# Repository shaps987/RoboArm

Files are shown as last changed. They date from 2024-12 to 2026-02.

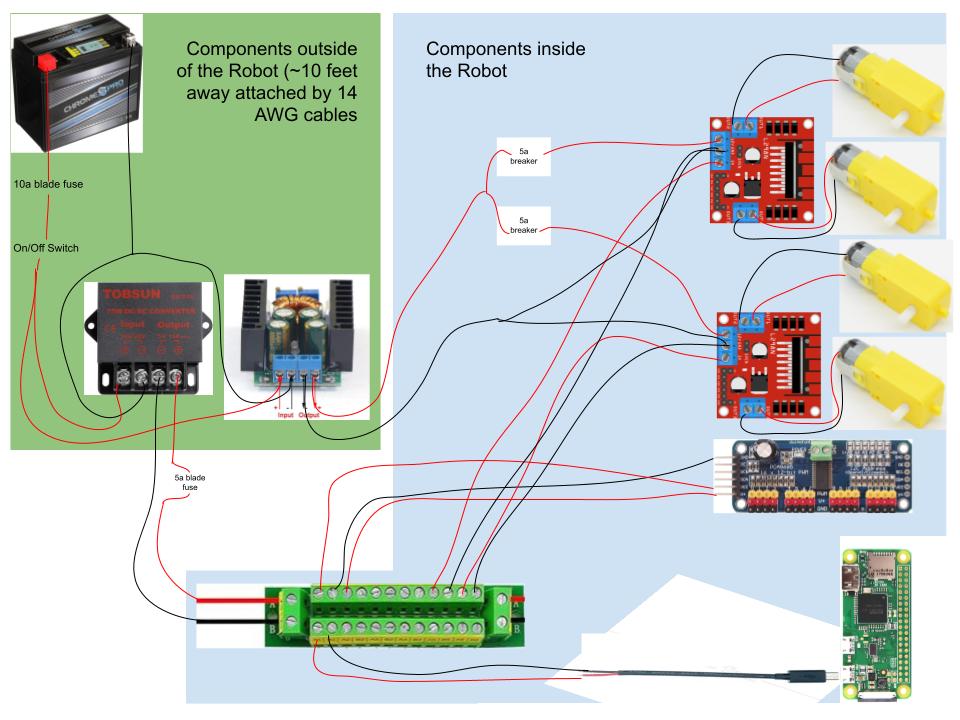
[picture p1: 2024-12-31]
Wiring/Robot/robot_wiring_diagram.jpg

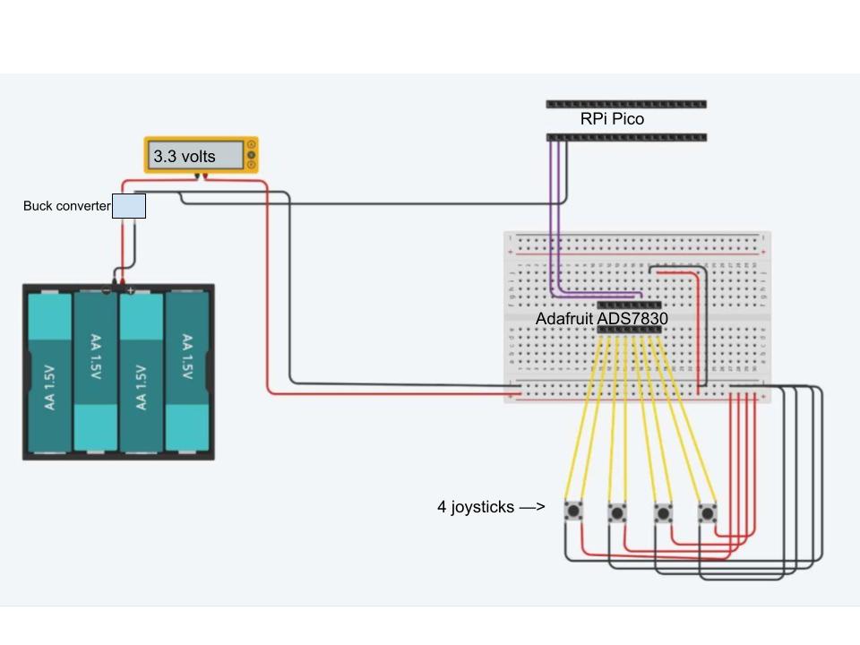
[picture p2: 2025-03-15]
Wiring/Remote/remote_wiring_diagram2.jpg

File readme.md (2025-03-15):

# RoboArm Project

## Overview
This project involves building a versatile and remotely controlled robotic arm, leveraging the power and flexibility of Raspberry Pi microcontrollers. The robotic arm is designed for precise movement and versatility, controlled remotely via a custom-built controller featuring multiple joysticks. The remote communicates with the robotic arm over Bluetooth Low Energy (BLE) for real-time command execution.

The **remote control** is powered by a Raspberry Pi Pico WH and includes an analog-to-digital converter to process joystick inputs. These joysticks allow intuitive control of the robotic arm's movements, including its base, joints, and claw.

The **robotic arm** itself is powered by a Raspberry Pi Zero WH, which coordinates the movements of servos and motors to execute commands received from the remote. With **inverse kinematics**, the robotic arm achieves smooth and accurate movement for tasks requiring precision. The arm is mounted on a mecanum wheel chassis, enabling it to move in all directions and navigate complex environments.

---

## Components

### Remote Control
- **Raspberry Pi Pico WH**: Used as the main controller for the remote.
- **Analog to Digital Converter (Adafruit ADS7830)**: Converts the analog signals from the joysticks to digital signals.
- **4 Joysticks**: Used to control the movement of the robotic arm.

### Robotic Arm
- **Raspberry Pi Zero WH**: Used as the main controller for the robotic arm.
- **4 Servos (MG996R)**:
  - 3 for the joints of the arm.
  - 1 for the claw's grippers.
- **2 Motor Controllers (L298N)**: Control a total of 4 mecanum wheel motors for the robotic arm's chassis.
- **Servo Controller (PCA9685)**: Controls the 4 servos.
- **1 12V Battery**: Powers the entire robotic arm system.
- **2 Buck Converters**:
  - One steps down from **12V to 5V** for logic circuits.
  - One steps down from **12V to 7V** for motor power.
- **Various Protection Devices**:
  - 1 **10A Slow-Blow Fuse** for the entire circuit.
  - 1 **5A Slow-Blow Fuse** for the logic circuit (RPi Zero, PCA9685 servo controller, and the logic inputs of both L298N motor drivers).
  - 2 **5A Circuit Breakers** for the motor circuits (one for each L298N).
- **Rocker Switch**

---

## Power Supply

### Remote Control
- Powered by a 6V 4 AA battery pack stepped down to 5V with a buck converter.

### Robotic Arm
- **12V Battery**:
  - The positive terminal is connected to a **10A slow-blow fuse**, chosen because the combined input current for the buck converters is ~7A, allowing for surges.
  - Powers two buck converters:
    - **Buck Converter #1 (5V)**:
      - Supplies the Raspberry Pi Zero, PCA9685, and logic inputs of both L298Ns.
      - Protected by a **5A slow-blow fuse**, chosen because the total current draw of these components is ~3.7A, with additional headroom for safety.
    - **Buck Converter #2 (7V)**:
      - Supplies the VIN inputs of both L298Ns for motor power.
      - Protected by **two 5A circuit breakers** (one per L298N motor driver, chosen because each driver can handle up to ~4A under normal operation, with peaks up to 5A during stalls or startups).

---

## Setup

### 1. Purchase Products
Here are the product links with their prices (prices may change):
| **Item** | **Price**  |
|---|---|
| [Chrome Battery YTX12-BS iGel](https://www.amazon.com/Chrome-Battery-iGel-12-BS-CYTX12-BS/dp/B01DOIULOO) | $39.90 |
| [Inline Blade Fuse Holder Set](https://www.amazon.com/GNAWRISHING-Inline-Holder-Standard-Assorted/dp/B09Y8GB799) | $8.99 |
| [5A Circuit Breaker (2-Pack)](https://www.amazon.com/mxuteuk-Breakers-Protector-Terminals-Waterproof/dp/B08QVCYLMD) | $9.99 |
| [Rocker Switch](https://www.amazon.com/gp/product/B07XD8J2PL) | $8.99 |
| [12V to 5V Buck Converter](https://www.amazon.com/VOLRANTISE-Converter-Voltage-Regulator-Transformer/dp/B09X1ZGR38) | $11.98 |
| [Adjustable Buck Converter (12V to 7V)](https://www.amazon.com/Converter-DROK-Adjustable-Regulator-Indicator/dp/B00HHQ0VP4) | $16.11  |
| [Power Distribution Board](https://www.amazon.com/Tnisesm-Position-Distribution-Inputs-Outputs/dp/B0BWN19R6R) | $8.99 |
| [Micro USB to Pigtail Cable](https://www.amazon.com/gp/product/B0BZ8XWL18/ref=ewc_pr_img_4?smid=A1PP7IW2YCJN73&psc=1) | $9.59 |
| [Raspberry Pi Zero WH](https://www.amazon.com/Raspberry-Bluetooth-Compatible-Connector-headers/dp/B0CG99MR5W) | $21.98 |
| [Momentary Push Button Switch with LED (5-pack)](https://www.amazon.com/Momentary-Indicator-Pushbutton-Waterproof-Stainless/dp/B08L13JG8M/) | $13.98 |
| [L298N Motor Drivers (4-pack)](https://www.amazon.com/gp/product/B0CR6MLY7F/ref=ewc_pr_img_7?smid=A1YZW40LYQY3L1&psc=1) | $9.99 |
| [Mecanum Wheels and Motors (4-pack)](https://www.amazon.com/gp/product/B0CBJJM1KQ/ref=ewc_pr_img_3?smid=A2S878EGP30YQG&th=1) | $15.60  |
| [PCA9685 Servo Driver (2-pack)](https://www.amazon.com/gp/product/B07BRS249H/ref=ewc_pr_img_8?smid=A30QSGOJR8LMXA&psc=1) | $13.99  |
| [MG996R Servos (4-Pack)](https://www.amazon.com/2-Pack-MG996R-Torque-Digital-Helicopter/dp/B0D7M2Y2BR) | $16.89 |
| [Adafruit 4 AA Battery Pack](https://www.adafruit.com/product/830) | $2.95 |
| [Adafruit Raspberry Pi Pico WH](https://www.adafruit.com/product/5544) | $7.00 |
| [Adafruit ADS7830 Analog to Digital Converter](https://www.adafruit.com/product/5836) | $5.95 |
| [Joysticks (6-pack)](https://www.amazon.com/gp/product/B0DH2G1PVP/ref=ewc_pr_img_6?smid=A3EW69KEBHQF24&psc=1) | $5.99 |
| [XT30 Connectors (8 pairs)](https://www.amazon.com/Pairs-Female-Connector-Silicone-Battery/dp/B07C5KJX24/) | $12.99 |

#### **Total Price: ~$243**

### 2. **Assemble the Remote Control**

- Connect the joysticks to the analog-to-digital converter.
- Connect the converter to the Raspberry Pi Pico.
- Power the Pico with the 6V battery pack stepped down to 5V.

### 3. **Assemble the Robotic Arm**
   - Connect the servos to the servo controller.
   - Connect the motor controllers to the mecanum wheel motors.
   - Connect the servo controller and motor controllers to the Raspberry Pi Zero.
   - Wire the **12V battery** as follows:
     - Connect the positive terminal to a **10A slow-blow fuse** then to a **rocker switch** and then split to two buck converters.
     - **Buck Converter #1 (5V)**:
       - Connect the positive output to the Raspberry Pi Zero, PCA9685, and logic inputs of both L298Ns.
       - Use a **5A slow-blow fuse** after the buck converter.
     - **Buck Converter #2 (7V)**:
       - Split the positive output into two separate wires, each passing through a **5A circuit breaker** before connecting to the VIN inputs of each L298N motor driver.
   - Use **14 AWG wires** for connections between the battery and the buck converters and from the buck converters along the ~10 feet (one-way) long powerline to the moving robot.
   - Use **18 AWG wires** for connections from the power distribution board to the components inside the robot.

---

## Usage
- Use the joysticks on the remote control to send signals to the Raspberry Pi Zero.
- The Raspberry Pi Zero processes these signals to control the servos and motors, moving the robotic arm accordingly.

---

## Future Improvements
- Add more sensors for better control and feedback.
- Enhance the software for more precise movements and automation.

---

## License
This project is licensed under the MIT License.

---

## Acknowledgements
Special thanks to the wonderful internet for providing many valuable resources for this project.

---

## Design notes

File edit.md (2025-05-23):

# Robotic Arm with nRF24L01⁺ (Pico ↔ nRF52840 Sense)

This README describes how to rewire and modify your project to use an **nRF24L01⁺** wireless transceiver instead of BLE, with:

- **Robot:** Raspberry Pi Pico running MicroPython  
- **Remote:** nRF52840 Sense running CircuitPython

---

## 1. Robot (Raspberry Pi Pico + MicroPython)

### 1.1 Wiring / Pin-out

| Function | Pico GP# | Physical Pin | Notes |
| --- | :---: | :---: | --- |
| **nRF24L01⁺**  | | | |
| VCC | — | 36 | 3.3 V |
| GND | — | 38 | Ground |
| CE | GP14 | 19 | Digital GPIO |
| CSN | GP15 | 20 | Active-low CS |
| SCK | GP18 | 24 | SPI0 SCK |
| MOSI | GP19 | 25 | SPI0 MOSI |
| MISO | GP16 | 21 | SPI0 MISO |
| **PCA9685** | | | |
| SDA | GP0 | 1 | I2C0 SDA |
| SCL | GP1 | 2 | I2C0 SCL |
| **L298N #1** | | | Controls 2 motors|
| IN1 | GP2 | 4 | |
| IN2 | GP3 | 5 | |
| IN3 | GP4 | 6 | |
| IN4 | GP5 | 7 | |
| ENA (PWM) | GP6 | 9 | PWM0 CH0 |
| ENB (PWM) | GP7 | 10 | PWM0 CH1 |
| **L298N #2** | | | Controls 2 motors|
| IN1 | GP8 | 11 | |
| IN2 | GP9 | 12 | |
| IN3 | GP10 | 14 | |
| IN4 | GP11 | 15 | |
| ENA (PWM) | GP12 | 16 | PWM0 CH2 |
| ENB (PWM) | GP13 | 17 | PWM0 CH3 |

---

### 1.2 Code Edits

1. **Remove BLE-related imports and `asyncio` logic**  
```python
# Remove these:
from bleak import BleakScanner, BleakClient
import asyncio
# and any `async def` connect_to_remote(), peripheral_task(), etc.
```

2. **Import nRF24L01⁺ and initialize SPI and RX logic**  
```python
import board, busio, digitalio, time
from adafruit_nrf24l01 import NRF24L01

spi = busio.SPI(board.SCK, board.MOSI, board.MISO)
ce = digitalio.DigitalInOut(board.GP14)
csn = digitalio.DigitalInOut(board.GP15)
radio = NRF24L01(spi, csn, ce, channel=100, payload_size=1)
radio.open_rx_pipe(0, b'\xe1\xf0\xf0\xf0\xf0')
```

3. **Replace BLE connection and main loop with a blocking `while True:` that reads from `radio`**  
```python
while True:
    if radio.available():
        buf = radio.read(1)
        cmd = bytes(buf)
        move_robot(cmd)
    time.sleep(0.1)
```

4. **Delete all BLE callbacks, `async def` functions, and BLE-specific error handling**

---

## 2. Remote (nRF52840 Sense + CircuitPython)

### 2.1 Wiring / Pin-out

| Function | Board Pin | Notes |
| --- | --- | --- |
| **ADS7830** | | |
| VCC | 3V3 | |
| GND | GND | |
| SDA | SDA | I²C SDA |
| SCL | SCL | I²C SCL |
| **nRF24L01⁺**  | | |
| VCC | 3V3 | |
| GND | GND | |
| CE | D5 | Digital IO |
| CSN | D6 | Active-low CS |
| SCK | SCK | SPI SCK |
| MOSI | MOSI | SPI MOSI |
| MISO | MISO | SPI MISO |

---

### 2.2 Code Edits

1. **Remove BLE-related imports and logic**  
```python
# Remove these:
from bleak import BleakScanner, BleakClient
import asyncio
# and any `async def` connect_to_remote(), peripheral_task(), etc.
```

2. **Import nRF24L01⁺ and initialize SPI and TX pipe**  
```python
import board, busio, digitalio, time
from adafruit_nrf24l01 import NRF24L01

spi = busio.SPI(board.SCK, board.MOSI, board.MISO)
ce = digitalio.DigitalInOut(board.D5)
csn = digitalio.DigitalInOut(board.D6)
radio = NRF24L01(spi, csn, ce, channel=100, payload_size=1)
radio.open_tx_pipe(b'\xe1\xf0\xf0\xf0\xf0')
```

3. **Replace BLE `notify` calls with `radio.send()` logic inside a `while True:`**  
```python
last_cmd = None
while True:
    val = ads.read(1)  # joystick forward/back
    if val > 148:
        cmd = b"f"
    elif val < 108:
        cmd = b"b"
    else:
        cmd = None

    if cmd and cmd != last_cmd:
        radio.send(cmd)
        last_cmd = cmd

    time.sleep(0.1)
```

4. **Delete `async def` functions and all BLE-specific control flow**

---

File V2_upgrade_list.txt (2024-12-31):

V2 Upgrade Suggestions

1. Add Limit Switches:
   - Install limit switches for safety and precise control at the arm's movement limits.
   - Connect to GPIO pins to detect end stops.

2. Improve Motor Control:
   - Upgrade L298Ns to motor drivers with higher efficiency (e.g., TB6612FNG) to reduce heat and improve performance.

3. Feedback Systems:
   - Add potentiometers or encoders to track servo/motor positions in real-time.

4. Battery Monitoring:
   - Use a voltage divider with an ADC or a dedicated battery monitoring IC to display battery level on the controller.

5. OLED Screen:
   - Add a 1.3-inch OLED screen to display status information (e.g., battery level, connection status).

6. Wi-Fi Connectivity:
   - Add a Wi-Fi module (e.g., ESP8266) for remote control and telemetry.

7. Sensor Integration:
   - Include sensors like ultrasonic or IR distance sensors for obstacle detection.

8. Camera Support:
   - Attach a Pi Camera for vision-based control or remote viewing.

9. Advanced Inverse Kinematics:
   - Improve software to handle more complex arm movements and path planning.

10. Voice Commands:
    - Add a microphone and integrate voice control using AI libraries (e.g., Google Speech-to-Text).

11. Chassis Upgrade:
    - Use better wheels or motors for smoother and more stable movement.

12. Parallel Movement Commands:
    - Enable the arm to process multiple movement commands simultaneously by placing each movement under its own asyncio task.

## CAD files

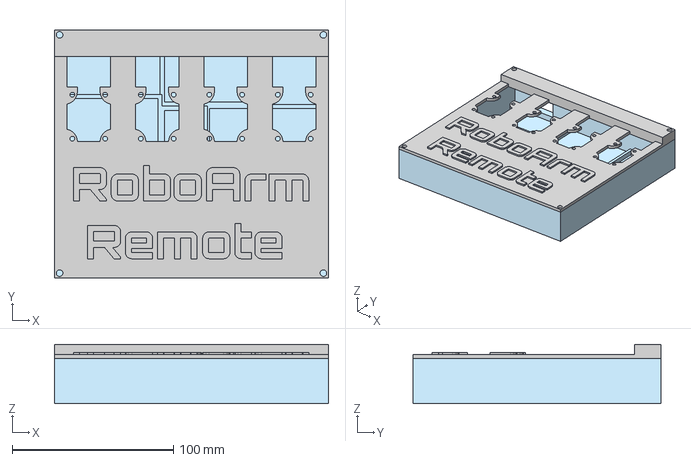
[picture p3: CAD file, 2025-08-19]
CAD Files/Remote/remote_assembled.step
169.9 x 154.1 x 36.8 mm

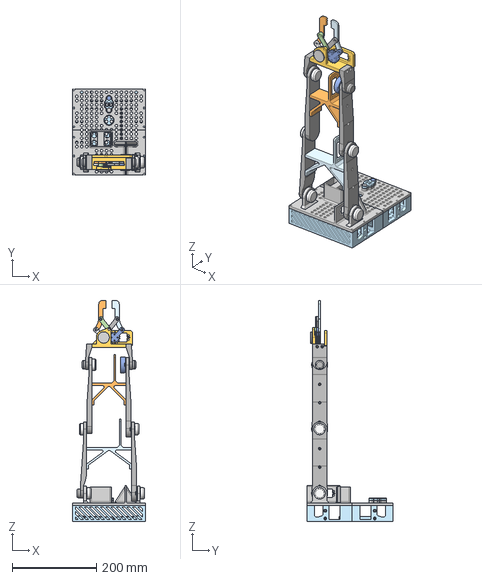
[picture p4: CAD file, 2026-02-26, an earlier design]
Archive/CAD Files OLD/Robot/robot_assembled.step
172.7 x 204.6 x 523.9 mm

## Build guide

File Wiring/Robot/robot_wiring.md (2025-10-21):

# Robotic Arm Wiring Description

---

### 12V 10.5Ah Battery(Power Source)

- **Amperage Usage**: Supplies ~7A for both buck converters.
- **Purpose**: Powers two buck converters, stepping down to **5V** for the logic circuits and **7V** for the motor inputs.
- **Connections**:
  - **Positive (+)**:
    - Connect to a **10A slow-blow fuse** (chosen because the total current draw from both buck converters is ~7A, allowing a safe margin for surges).
    - From the fuse, connect to a **rocker switch** using the wires pre-soldered to the switch.
    - After the switch, split the positive line into two separate connections for the two buck converters.
    - Use 18 AWG wire for connections up to the switch and split point.
  - **Negative (-)**:
    - Split the negative line and connect to the negative input of both buck converters.
    - Use 14 AWG wire to minimize voltage drop.

---

### Buck Converter #1 (5V for Logic Circuits)

- **Amperage Usage**: Draws ~5.4A at 5V.
  - **Breakdown**:
    - **L298N Logic**: ~0.1A (50mA × 2 motor drivers).
    - **Raspberry Pi Pico**: ~0.2A.
    - **PCA9685 Servo Controller (Logic)**: ~0.3A.
    - **Servos (MG996R)**: ~4.8A (1.2A × 4 servos).
    - **Momentary LED Push Button**: ~20mA when lit.
- **Purpose**: Steps down 12V to 5V for powering the Raspberry Pi Pico, PCA9685, and L298N logic circuits.
- **Connections**:
  - **Input**:
    - **Positive (+)**: Connect to the + terminal of the 12V battery via the split positive wire.
    - **Negative (-)**: Connect to the negative terminal of the 12V battery via the split negative wire.
    - Use 14 AWG wires for input.
  - **Output (5V)**:
    - Pass through a **5A slow-blow fuse** (chosen because the total current draw of the Raspberry Pi Pico, PCA9685, and L298N logic inputs is ~3.7A at 5V, with additional headroom for safety).
    - Use 14 AWG ~10 foot long cables to bring power to the moving robot from the buck converter.
      - Connect to a power distribution block:
        - **Positive (+)**:
          - The 5V logic input of both L298Ns.
          - The 5V input of the Raspberry Pi Pico.
          - The 5V input of the PCA9685 servo controller.
          - Use 18 AWG wires for these connections.
        - **Negative (-)**:
          - The GND terminal on both L298Ns.
          - The GND wire for the Raspberry Pi Pico's power.
          - The GND terminal on the PCA9685 servo controller.
          - Use 18 AWG wires for these connections.

---

### Buck Converter #2 (7V for Motor Inputs)

- **Amperage Usage**: Supplies ~4.8A for motor inputs.
- **Purpose**: Steps down 12V to 7V for powering the VIN inputs on both L298Ns.
- **Connections**:
  - **Input**:
    - **Positive (+)**:
      - Connect to the + terminal of the 12V battery via the split positive wire.
      - Use **14 AWG wires** for this connection.
    - **Negative (-)**:
      - Connect to the negative terminal of the 12V battery via the split negative wire.
      - Use **14 AWG wires** for this connection.
  - **Output (7V)**:
    - **Positive (+)**:
      - Split the **14 AWG wire** into two **18 AWG wires**.
      - Pass each of the **18 AWG wires** through a **5A circuit breaker**, one for each motor driver.
      - Connect the output of each breaker to the VIN input of its respective **L298N motor driver**.
    - **Negative (-)**:
      - Split the negative wire and connect to the GND terminals of both motor drivers using **18 AWG wire**.

---

### Momentary Push Button with LED

- **Amperage Usage**: The LED draws ~20mA when lit.
- **Purpose**: Allows the user to safely stop the script and shut down the Raspberry Pi.
- **Connections**:
  - **Positive (+)**:
    - Connect the LED positive terminal (red wire) to the 5V output of the power distribution block.
  - **Negative (-)**:
    - Connect the LED negative terminal (black wire) to the GND on the power distribution block.
  - **NO (Blue)**:
    - Connect the Normally Open terminal to a GPIO pin on the Raspberry Pi Zero.

---

### L298N Motor Drivers

1. **L298N #1**:
   - **Amperage Usage**:
     - **VIN (Motor Power Input)**: Draws ~1.2A during normal operation to power two motors.
     - **5V Logic Input**: Draws ~0.05A (50mA) to power the logic circuitry.
   - **Connections**:
     - **VIN (Motor Power Input)**:
       - Connect to the 7V output of the second buck converter after its dedicated **5A slow-blow fuse**.
       - Use 14 AWG wire.
     - **5V Logic Input**:
       - Connect to the +5V output of the first buck converter after the combined **5A slow-blow fuse**.
       - Use 18 AWG wire.
     - **GND**:
       - Connect to the GND output of the first buck converter.
       - Connect to the GND output of the second buck converter.
       - Use 18 AWG wire.

2. **L298N #2**:
   - **Amperage Usage**:
     - **VIN (Motor Power Input)**: Draws ~1.2A during normal operation to power two motors.
     - **5V Logic Input**: Draws ~0.05A (50mA) to power the logic circuitry.
   - **Connections**:
     - **VIN (Motor Power Input)**:
       - Connect to the 7V output of the second buck converter after its dedicated **5A slow-blow fuse**.
       - Use 14 AWG wire.
     - **5V Logic Input**:
       - Connect to the +5V output of the first buck converter after the combined **5A slow-blow fuse**.
       - Use 18 AWG wire.
     - **GND**:
       - Connect to the GND output of the first buck converter.
       - Connect to the GND output of the second buck converter.
       - Use 18 AWG wire to connect to the respective 14 AWG wire bringing power from the buck converter to the robot.

---

### Raspberry Pi Pico

- **Purpose**: Controls the robotic arm's servos and motor drivers (L298Ns).
- **Connections**:
  - **5V Power Input**:
    - Connect to the +5V output of the first buck converter through the **power distribution block**.
    - Use 18 AWG wire.
  - **GND**:
    - Connect to the GND output of the first buck converter through the **power distribution block**.
    - Use 18 AWG wire.

---

### PCA9685 Servo Controller

- **Amperage Usage**: Draws ~0.3A at 5V (logic only; servos powered separately).
- **Purpose**: Controls the servos on the robotic arm.
- **Connections**:
  - **5V Power Input**:
    - Connect to the +5V output of the first buck converter through the **power distribution block**.
    - Use 18 AWG wire.
  - **GND**:
    - Connect to the GND output of the first buck converter through the **power distribution block**.
    - Use 18 AWG wire.
  - **Servo Pins**:
    - Connect the servos (e.g., MG996R) directly to the PCA9685.

---

### Servos (MG996R)

- **Amperage Usage**: Draws ~1.2A per servo at 5V (when loaded; ~0.5A idle).
- **Purpose**: Provide movement for the robotic arm joints and claw.
- **Connections**:
  - **Power, GND, and PWM**:
    - Powered and controlled directly by the PCA9685.
    - Servos come with built-in wires and connectors.

---

### Motors (TT Motors via L298N)

- **Amperage Usage**: Each motor draws ~1.2A at 7V (under normal load; peaks ~3A).
- **Purpose**: Drive the robot chassis with mecanum wheels.
- **Connections**:
  - Each motor is connected to one of the motor output terminals on the L298Ns:
    - **Motor 1**: L298N #1 Output 1 & Output 2.
    - **Motor 2**: L298N #1 Output 3 & Output 4.
    - **Motor 3**: L298N #2 Output 1 & Output 2.
    - **Motor 4**: L298N #2 Output 3 & Output 4.
  - Use 18 AWG wires for motor connections.

---

### Wiring Chart - THE FOLLOWING PINS ARE OUTDATED (THEY ARE FOR THE RPI ZERO VERSION, NOT THE PICO VERSION)
Voltage Distribution Unit:
  - Positive Terminal of Battery: To 10A Fuse
  - Negative Terminal of Battery: Splits and goes to the 2 buck converters
  - 10A Fuse: To switch
  - Switch: splits and goes to the 2 buck converters
  - 7V Buck Converter Positive Output: To robot, then splits into two wires. Each wire has a 5A fuse on it. And then each fuse goes into the 12V pin on its respective L298N
  - 7V Buck Converter Negative Output: To robot, then splits into two wires. Then each wire goes into the 12V pin on its respective L298N
Motor Driver 1:
  - ENA: Pin 32, GPIO12
  - IN1: Pin 29, GPIO5
  - IN2: Pin 31, GPIO6
  - ENB: Pin 33, GPIO13
  - IN3: Pin 35, GPIO19
  - IN4: Pin 37, GPIO26

Motor Driver 2:
  - ENA: Pin 12, GPIO18
  - IN1: Pin 16, GPIO23
  - IN2: Pin 18, GPIO24
  - ENB: Pin 22, GPIO25
  - IN3: Pin 13, GPIO27
  - IN4: Pin 15, GPIO22

PCA9685:
  - SDA: Pin 3, GPIO2
  - SCL: Pin 5, GPIO3
  - VCC: 3.3v pin on Raspberry Pi Pico
  - GND: Ground pin on Raspberry Pi PIco
  - V+ (on the PCA9685 terminal block): 5V distribution block
  - GND (on the PCA9685 terminal block): 5V distribution block

NRF24L01:
  - VCC: Pin 36
  - GND: Pin 38
  - CE: Pin 19, GPIO 14
  - CSN: Pin 20, GPIO 15
  - SCK: Pin 24, GPIO 18
  - MOSI: Pin 25, GPIO 19
  - MISO: Pin 21, GPIO 16
  - IRQ: Not used

5V Distribution Block:
  - +/- Input: 5V Buck Converter +/- Output
  - +/- Outputs:
    - To Raspberry Pi Pico via a Pigtail to Micro-USB cable
    - To L298N #1 5V Logic Input and GND terminals
    - To L298N #2 5V Logic Input and GND terminals
    - To PCA9685 +/- V+ terminal block

### Final Checklist

1. **12V Battery** powers both buck converters:
   - Buck Converter #1 (5V): Supplies the Raspberry Pi Pico, PCA9685, and L298N logic inputs.
   - Buck Converter #2 (7V): Supplies the VIN inputs (motor power) on both L298Ns.
2. **Fuses**:
   - **10A Slow-Blow Fuse**: Protects the entire circuit, chosen because the combined input current for both buck converters is ~7A.
   - **5A Slow-Blow Fuse** (Logic Circuit): Protects the Raspberry Pi Pico, PCA9685, and L298N logic inputs.
   - **5A Slow-Blow Fuses** (Motor Drivers): One fuse per L298N motor driver, chosen because each driver can handle up to ~4A continuously with peaks up to 5A during stalls or startups.
3. **Switch**:
   - Use an 18 AWG wire to connect the positive terminal of the battery to the switch and the switch to the fuse.
4. **Wiring to the Robot**:
   - Use 14 AWG wires for the long runs to the robot's power distribution blocks.
   - Inside the robot, use 18 AWG wires to connect components to the distribution blocks.

---

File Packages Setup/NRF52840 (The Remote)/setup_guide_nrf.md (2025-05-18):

# nRF52840 BLE Project Setup with ADS7830 and CircuitPython

This guide walks you through flashing firmware, setting up libraries, wiring the hardware, and loading the code for your nRF52840 board running CircuitPython with BLE support and an ADS7830 sensor.

---

## 1. Flash CircuitPython Firmware

1. **Download Firmware:**
   - Visit [CircuitPython Downloads](https://circuitpython.org/downloads) and locate the appropriate UF2 file for your nRF52840 board.
   - **Note:** If you're using a board like the Adafruit nRF52840 Sense, use its UF2 file. For other variants (e.g., Seeed Studio XIAO nRF52840), you may need a custom or community-provided firmware.

2. **Enter Bootloader Mode:**
   - For many nRF52840 boards, double‑tap the reset button. The board will appear as a USB mass storage device (commonly named **CIRCUITPY**).

3. **Copy the UF2 File:**
   - Drag and drop the UF2 file onto the board’s drive. The board will reboot into CircuitPython.

---

## 2. Prepare Your Libraries

1. **Create or Update the `lib` Folder:**
   - On the **CIRCUITPY** drive, ensure there is a folder named `lib`.

2. **Download Required Libraries:**
   - Just take the pre-made lib folder in this github repository (its in packages setup -> nrf52840 (the remote) -> files -> lib)

---

## 3. Hardware Wiring

### ADS7830 Sensor
- **Power:** Connect the ADS7830 VDD to your board’s 3.3V output and GND to the board’s ground.
- **I2C Lines:**
  - **SDA:** Connect ADS7830 SDA to the board’s SDA pin (usually referenced as `board.SDA`).
  - **SCL:** Connect ADS7830 SCL to the board’s SCL pin (usually referenced as `board.SCL`).

### LED Indicator (Optional)
- Most boards include a built-in LED referenced as `board.LED`. Confirm with your board's documentation.

---

## 4. Write and Load Your Code

1. **Create Your Main Script:**
   - On the **CIRCUITPY** drive, create a file named `code.py`.

2. **Paste the Following Code into `code.py`:**

   ```python
    import board
    import digitalio
    import busio
    import microcontroller
    import asyncio

    # --- BLE Imports from Adafruit Libraries ---
    from adafruit_ble import BLERadio, Service
    from adafruit_ble.advertising.standard import ProvideServicesAdvertisement
    from adafruit_ble.characteristics import Characteristic
    from adafruit_ble.uuid import StandardUUID
    from adafruit_ble.services.standard.device_info import DeviceInfoService

    # I²C address discovered by scan
    ADS7830_ADDR = 0x48

    # --- I2C Setup for ADS7830 ---
    i2c = busio.I2C(board.SCL, board.SDA)
    ads7830_commands = (0x84, 0xC4, 0x94, 0xD4, 0xA4, 0xE4, 0xB4, 0xF4)

    def read_ads7830(channel):
        """Read one byte from the given ADS7830 channel over I2C."""
        while not i2c.try_lock():
            pass
        try:
            i2c.writeto(ADS7830_ADDR, bytes([ads7830_commands[channel]]))
            buf = bytearray(1)
            i2c.readfrom_into(ADS7830_ADDR, buf)
            return buf[0]
        except Exception as e:
            print("I2C error:", e)
            return 0
        finally:
            i2c.unlock()

    def uid():
        """Return the unique id of the device as a string."""
        return "".join("{:02x}".format(x) for x in microcontroller.cpu.uid)

    # --- BLE Constants ---
    _BLE_APPEARANCE_GENERIC_REMOTE_CONTROL = 384

    # --- Define a Custom BLE Service ---
    class RemoteService(Service):
        # 16-bit service UUID is fine here
        uuid = StandardUUID(0x1848)

        # use StandardUUID for the char, and override to 1 byte
        button = Characteristic(
            uuid=StandardUUID(0x2A6E),                     # spec-assigned 16-bit
            properties=Characteristic.READ | Characteristic.NOTIFY,
            max_length=1                                    # allow exactly one byte
        )

    remote_service = RemoteService()
    device_info = DeviceInfoService(
        manufacturer="RoboticArmRemote",
        model_number="1.0",
        serial_number=uid(),
        hardware_revision="1.0",
        firmware_revision="1.0",
    )

    # --- Hardware LED Setup ---
    led = digitalio.DigitalInOut(board.LED)
    led.direction = digitalio.Direction.OUTPUT

    # Global BLE state
    ble = BLERadio()
    connected = False

    # --- BLE Peripheral Task ---
    async def peripheral_task():
        global connected
        advertisement = ProvideServicesAdvertisement(remote_service, device_info)
        advertisement.appearance = _BLE_APPEARANCE_GENERIC_REMOTE_CONTROL
        advertisement.complete_name = "RoboticArmRemote"
        ble.start_advertising(advertisement)
        while True:
            if ble.connected:
                conn = ble.connections[0]
                connected = True
                print("Connected to:", conn)
                while ble.connected:
                    await asyncio.sleep(0.1)
                connected = False
                print("Disconnected")
                ble.start_advertising(advertisement)
            await asyncio.sleep(0.1)

    # Dead-zone thresholds
    CENTER   = 128
    DEADZONE = 20
    UPPER    = CENTER + DEADZONE
    LOWER    = CENTER - DEADZONE
    _last_button = None

    # --- Remote Task ---
    async def remote_task():
        global connected, _last_button
        while True:
            if not connected:
                print("Not Connected")
                await asyncio.sleep(1)
                continue

            try:
                # Read & map exactly like before...
                chassis_fb     = read_ads7830(1)
                chassis_strafe = read_ads7830(0)
                chassis_turn   = read_ads7830(2)
                arm_fb         = read_ads7830(5)
                claw           = read_ads7830(4)
                arm_ud         = read_ads7830(7)

                # Decide which single-byte command to send
                cmd = None
                if chassis_fb >  UPPER:
                    print("Joystick 1 → Chassis Forward")
                    cmd = b"f"
                elif chassis_fb <  LOWER:
                    print("Joystick 1 → Chassis Backward")
                    cmd = b"b"

                if chassis_strafe >  UPPER:
                    print("Joystick 1 → Chassis Strafe Right")
                    cmd = b"r"
                elif chassis_strafe <  LOWER:
                    print("Joystick 1 → Chassis Strafe Left")
                    cmd = b"l"

                if chassis_turn >  UPPER:
                    print("Joystick 2 → Chassis Turning Left")
                    cmd = b"p"
                elif chassis_turn <  LOWER:
                    print("Joystick 2 → Chassis Turning Right")
                    cmd = b"q"

                if arm_fb >  UPPER:
                    print("Joystick 3 → Arm Backward")
                    cmd = b"c"
                elif arm_fb <  LOWER:
                    print("Joystick 3 → Arm Forward")
                    cmd = b"a"

                if claw >  UPPER:
                    print("Joystick 3 → Claw Open")
                    cmd = b"y"
                elif claw <  LOWER:
                    print("Joystick 3 → Claw Closed")
                    cmd = b"z"

                if arm_ud >  UPPER:
                    print("Joystick 4 → Arm Down")
                    cmd = b"e"
                elif arm_ud <  LOWER:
                    print("Joystick 4 → Arm Up")
                    cmd = b"d"

                # If we got a new command and it's different, send it
                if cmd is not None and cmd != _last_button:
                    remote_service.button = cmd
                    _last_button = cmd

            except Exception as e:
                print("Error in remote_task:", e)

            await asyncio.sleep(0.1)

    # --- LED Blink Task ---
    async def blink_task():
        toggle = True
        while True:
            led.value = toggle
            toggle = not toggle
            await asyncio.sleep(1.0 if connected else 0.25)

    # --- Main Entry Point ---
    async def main():
        await asyncio.gather(
            peripheral_task(),
            remote_task(),
            blink_task(),
        )

    if __name__ == "__main__":
        try:
            asyncio.run(main())
        except KeyboardInterrupt:
            print("Exiting…")
        finally:
            print("Cleaning up…")

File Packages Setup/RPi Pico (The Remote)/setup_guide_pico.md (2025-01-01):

Installing the usmbus Library on Raspberry Pi Pico
--------------------------------------------------

This document details the steps to download and install the `usmbus` library on a Raspberry Pi Pico. The library enables I2C communication for devices like the ADS7830 ADC.

* * * * *

Prerequisites
-------------

-   Raspberry Pi Pico with MicroPython installed.
-   MicroPython REPL accessible via `mpremote`.
-   A development computer with Python installed and access to a terminal.

* * * * *

Steps
-----

### 1\. Download the usmbus Library

1.  Go to the [usmbus GitHub repository](https://github.com/mcauser/micropython-smbus) on your computer.
2.  Download the repository as a ZIP file:
    -   Click the green "Code" button and select **Download ZIP**.
3.  Extract the ZIP file to access the library source files.

Or just drag the lib folder with the neccessary package included in this github repository into your Pico via an IDE like Thonny. From there, you can import usumbus as normal.

* * * * *

### 2\. Copy the Library Files to the Pico

1.  Connect your Raspberry Pi Pico to your computer via USB.
2.  Confirm that your Pico is detected:

Bash

```
mpremote connect list

```

Note the COM port or device path of your Pico.

1.  Create a `/lib` directory on the Pico (if it doesn't already exist):

Bash

```
mpremote connect <COM_PORT> fs mkdir /lib

```

Replace `<COM_PORT>` with the detected port or device path.

1.  Copy the `usmbus` library folder to the Pico:

Bash

```
mpremote connect <COM_PORT> fs cp -r path/to/micropython-smbus/usmbus /lib/

```

Replace `path/to/micropython-smbus` with the path where you extracted the library.

### 3\. Verify Installation

Open the Pico's REPL:

Bash

```
mpremote connect <COM_PORT> repl

```

Test importing the library:

Python

```
>>> from usmbus import SMBus
>>> bus = SMBus(0)
>>> print(bus)

```

If there are no errors, the library is successfully installed.

* * * * *

Automating Script Execution on Startup
--------------------------------------

1.  Rename your MicroPython script to `main.py`:

Bash

```
mv your_script.py main.py

```

1.  Copy the script to the Pico:

Bash

```
mpremote connect <COM_PORT> fs cp path/to/main.py /

```

The script will now execute automatically when the Pico is powered on.

* * * * *

Troubleshooting
---------------

**Error: Module not found**

-   Ensure the library folder is copied to the `/lib` directory on the Pico.
-   Verify the Pico is running MicroPython.

**Connection Issues**

-   Check USB connections and ensure the correct COM port is used.
-   Run `mpremote connect list` to verify the Pico is detected.

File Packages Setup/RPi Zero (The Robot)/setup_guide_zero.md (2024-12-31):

# Installing Libraries and Setting Up Startup Script for Robot Script

## Step 1: Update and Upgrade System
Ensure the system is updated:
```bash
sudo apt update && sudo apt upgrade -y
```

---

## Step 2: Install Python 3 and Essential Tools
Install Python 3 and pip if not already installed:
```bash
sudo apt install python3 python3-pip python3-venv -y
```

---

## Step 3: Set Up a Virtual Environment
Create and activate a virtual environment:
```bash
python3 -m venv myenv
source myenv/bin/activate
```

---

## Step 4: Install Required Libraries

### 4.1 Install NumPy
Install NumPy for numerical computations:
```bash
pip install numpy
```

### 4.2 Install Adafruit PCA9685 Library
Install the Adafruit PCA9685 library for servo control:
```bash
pip install adafruit-circuitpython-pca9685
```

### 4.3 Install busio and board Modules
Install the Adafruit Blinka package, which includes `busio` and `board` modules for CircuitPython compatibility:
```bash
pip install adafruit-blinka
```

### 4.4 Install Bleak
Install Bleak for Bluetooth Low Energy (BLE) communication:
```bash
pip install bleak
```

### 4.5 Install RPi.GPIO
Install RPi.GPIO for Raspberry Pi GPIO pin control:
```bash
pip install RPi.GPIO
```

---

## Step 5: Enable I2C on Raspberry Pi
Enable I2C using the Raspberry Pi configuration tool:

1. Open the configuration tool:
   ```bash
   sudo raspi-config
   ```

2. Navigate to **Interface Options > I2C** and enable it.

3. Reboot the system:
   ```bash
   sudo reboot
   ```

---

## Step 6: Test I2C
Check if I2C devices are detected:

1. Install I2C tools:
   ```bash
   sudo apt install i2c-tools -y
   ```

2. Run the following command to detect connected devices:
   ```bash
   i2cdetect -y 1
   ```

---

## Step 7: Check BLE Compatibility
Ensure BLE hardware is functioning by scanning for BLE devices:

1. Check for BLE devices:
   ```bash
   hcitool lescan
   ```

2. If `hcitool` is not found, install Bluetooth tools:
   ```bash
   sudo apt install bluetooth bluez -y
   ```

---

## Step 8: Make the Script Executable
Navigate to the directory where your script is located and make it executable:

1. Change file permissions:
   ```bash
   chmod +x /path/to/your/script.py
   ```

2. Verify the script is now executable:
   ```bash
   ls -l /path/to/your/script.py
   ```

   Ensure the file's permissions include `-rwxr-xr-x`.

---

## Step 9: Set Up the Script as a Startup Service

### 9.1 Create a Systemd Service File
Create a service file in `/etc/systemd/system`:
```bash
sudo nano /etc/systemd/system/robot.service
```

Add the following content, adjusting paths as necessary:
```plaintext
[Unit]
Description=Robotic Arm Startup Script
After=network.target

[Service]
ExecStart=/home/pi/myenv/bin/python3 /path/to/your/script.py
WorkingDirectory=/path/to/your/script
StandardOutput=inherit
StandardError=inherit
Restart=always
User=pi

[Install]
WantedBy=multi-user.target
```

### 9.2 Enable the Service
Enable the service to run at startup:
```bash
sudo systemctl enable robot.service
```

### 9.3 Start the Service
Start the service immediately:
```bash
sudo systemctl start robot.service
```

### 9.4 Verify the Service
Check the status to ensure it is running:
```bash
sudo systemctl status robot.service
```

---

## Step 10: Run the Script Manually (Optional)
You can manually run the script for testing:
```bash
source myenv/bin/activate
python3 /path/to/your/script.py
```

---

## Final Notes
If everything is configured correctly, the script will start automatically on reboot. To stop the service, use:
```bash
sudo systemctl stop robot.service
```

To disable the service from starting at boot:
```bash
sudo systemctl disable robot.service

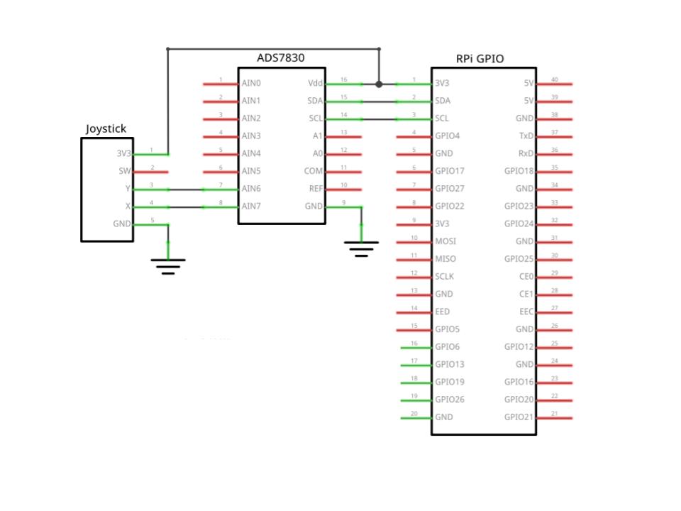
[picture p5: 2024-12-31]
Wiring/Remote/remote_wiring_diagram1.jpg

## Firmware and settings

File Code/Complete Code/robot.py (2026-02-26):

# --- 0. Imports ---
import math
import board
import busio
import time
import pwmio
from adafruit_pca9685 import PCA9685
from digitalio import DigitalInOut, Direction
from circuitpython_nrf24l01.rf24 import RF24

# --- 1. Robot Arm Constants ---
l1, l2, l3 = 6.0, 6.0, 2.0  
current_x = 8.0
current_y = 6.0

# --- 2. Hardware Setup (I2C, SPI, Radio) ---
i2c = busio.I2C(board.GP1, board.GP0)
pca = PCA9685(i2c)
pca.frequency = 50

spi = busio.SPI(board.GP18, board.GP19, board.GP16)
ce = DigitalInOut(board.GP14); ce.direction = Direction.OUTPUT
csn = DigitalInOut(board.GP15); csn.direction = Direction.OUTPUT

radio = RF24(spi, csn, ce)
radio.channel = 100
radio.payload_size = 1
radio.open_rx_pipe(1, b'\xe1\xf0\xf0\xf0\xf0')
radio.listen = True

# --- 3. Motor Controller Setup (Explicit Pin Mapping) ---
in1_1 = DigitalInOut(board.GP2); in1_1.direction = Direction.OUTPUT
in2_1 = DigitalInOut(board.GP3); in2_1.direction = Direction.OUTPUT
in3_1 = DigitalInOut(board.GP4); in3_1.direction = Direction.OUTPUT
in4_1 = DigitalInOut(board.GP5); in4_1.direction = Direction.OUTPUT
ena_1 = pwmio.PWMOut(board.GP6, frequency=100); ena_1.duty_cycle = 49151
enb_1 = pwmio.PWMOut(board.GP7, frequency=100); enb_1.duty_cycle = 49151

in1_2 = DigitalInOut(board.GP8); in1_2.direction = Direction.OUTPUT
in2_2 = DigitalInOut(board.GP9); in2_2.direction = Direction.OUTPUT
in3_2 = DigitalInOut(board.GP10); in3_2.direction = Direction.OUTPUT
in4_2 = DigitalInOut(board.GP13); in4_2.direction = Direction.OUTPUT
ena_2 = pwmio.PWMOut(board.GP12, frequency=100); ena_2.duty_cycle = 49151
enb_2 = pwmio.PWMOut(board.GP11, frequency=100); enb_2.duty_cycle = 49151

all_motors = [in1_1, in2_1, in3_1, in4_1, in1_2, in2_2, in3_2, in4_2]

# --- 4. Core Functions ---
def set_servo(channel, angle):
    angle = max(0, min(180, angle))
    min_pulse, max_pulse = 500, 2500
    pulse_width = int(min_pulse + (angle / 180.0) * (max_pulse - min_pulse))
    duty_cycle = int((pulse_width / 1000000) * pca.frequency * 65536)
    pca.channels[channel].duty_cycle = duty_cycle

def calculate_ik(x, y):
    x_adj = x - l3
    y_adj = y
    r_adj = math.sqrt(x_adj**2 + y_adj**2)

    # Law of Cosines
    cos_angle2 = (r_adj**2 - l1**2 - l2**2) / (2 * l1 * l2)
    angle2 = math.acos(max(-1.0, min(1.0, cos_angle2)))
    angle1 = math.atan2(y_adj, x_adj) - math.atan2(l2 * math.sin(angle2), l1 + l2 * math.cos(angle2))

    # Mirrored Logic
    joint2_x = l1 * math.cos(angle1) + l2 * math.cos(angle1 + angle2)
    joint2_y = l1 * math.sin(angle1) + l2 * math.sin(angle1 + angle2)
    line_angle = math.atan2(joint2_y, joint2_x)

    angle1 = 2 * line_angle - angle1
    angle2 = -angle2
    angle3 = -(angle1 + angle2)

    # Conversion to Degrees
    a1_deg, a2_deg, a3_deg = math.degrees(angle1), math.degrees(angle2), math.degrees(angle3)
    
    # Mapping based on your mirrored logic formulas
    s1 = 90 - (-1 * (90 - a1_deg))
    s2 = 90 + (-1 * (a2_deg + 90))
    s3 = 90 - a3_deg
    return s1, s2, s3

def move_robot(cmd):
    global current_x, current_y
    step = 0.5
    
    # --- Chassis Controls ---
    if cmd == b'f':
        in1_1.value, in2_1.value, in3_1.value, in4_1.value = False, True, True, False
        in1_2.value, in2_2.value, in3_2.value, in4_2.value = False, True, True, False
    elif cmd == b'b':
        in1_1.value, in2_1.value, in3_1.value, in4_1.value = True, False, False, True
        in1_2.value, in2_2.value, in3_2.value, in4_2.value = True, False, False, True
    elif cmd == b'r':  # Strafe Right
        in1_1.value, in2_1.value, in3_1.value, in4_1.value = True, False, True, False
        in1_2.value, in2_2.value, in3_2.value, in4_2.value = True, False, True, False
    elif cmd == b'l':  # Strafe Left
        in1_1.value, in2_1.value, in3_1.value, in4_1.value = False, True, False, True
        in1_2.value, in2_2.value, in3_2.value, in4_2.value = False, True, False, True
    elif cmd == b'q':  # turn right (in place)
        in1_1.value, in2_1.value, in3_1.value, in4_1.value = True, False, False, True
        in1_2.value, in2_2.value, in3_2.value, in4_2.value = False, True, True, False

    elif cmd == b'p':  # turn left (in place)
        in1_1.value, in2_1.value, in3_1.value, in4_1.value = False, True, True, False
        in1_2.value, in2_2.value, in3_2.value, in4_2.value = True, False, False, True

    elif cmd == b"s":  # STOP
        in1_1.value = in2_1.value = in3_1.value = in4_1.value = False
        in1_2.value = in2_2.value = in3_2.value = in4_2.value = False

    # --- Arm Movement ---
    elif cmd in [b'a', b'c', b'd', b'e']:
        if cmd == b'a': current_x += step
        elif cmd == b'c': current_x -= step
        elif cmd == b'd': current_y += step
        elif cmd == b'e': current_y -= step
        
        # Reach limit clamp (Total length is 12)
        current_x = max(2.0, min(11.5, current_x))
        current_y = max(1.0, min(11.0, current_y))
        
        s1, s2, s3 = calculate_ik(current_x, current_y)
        set_servo(12, s1)
        set_servo(13, s2)
        set_servo(14, s3)

    elif cmd == b'y': 
        set_servo(15, 45) # Claw Open
    elif cmd == b'z': 
        set_servo(15, 0)  # Claw Closed

# --- 5. Main Loop ---
print("System Ready.")
# Sync servos to start position
set_servo(12, 90); set_servo(13, 90); set_servo(14, 90)

while True:
    if radio.available():
        # While there is data in the radio's hardware buffer...
        while radio.available():
            buf = radio.read(1)
            move_robot(buf)
            # Small delay so it doesn't move TOO fast while clearing the buffer
            time.sleep(0.005) 
    else:
        # If no signal is received, we can optionally stop the chassis
        # but keep this light so the arm doesn't jitter.
        pass
    
    time.sleep(0.01)

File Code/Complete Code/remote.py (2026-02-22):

# --- Imports --- #
import board, busio, digitalio, time
from circuitpython_nrf24l01.rf24 import RF24

# --- Initialize SPI and TX Pipe --- #
spi = busio.SPI(board.SCK, board.MOSI, board.MISO)
ce = digitalio.DigitalInOut(board.D1)
csn = digitalio.DigitalInOut(board.D0)
radio = RF24(spi, csn, ce)
radio.channel      = 100      # 0–125
radio.payload_size = 1        # one-byte packets
print("TX: channel =", radio.channel, "addr =", b"\xe1\xf0\xf0\xf0\xf0", 
      "payload_size =", radio.payload_size)
radio.open_tx_pipe(b'\xe1\xf0\xf0\xf0\xf0')
radio.listen = False

# I²C address discovered by scan
ADS7830_ADDR = 0x48

# --- I2C Setup for ADS7830 ---
i2c = busio.I2C(board.SCL, board.SDA)
ads7830_commands = (0x84, 0xC4, 0x94, 0xD4, 0xA4, 0xE4, 0xB4, 0xF4)

def read_ads7830(channel):
    """Read one byte from the given ADS7830 channel over I2C."""
    while not i2c.try_lock():
        pass
    try:
        i2c.writeto(ADS7830_ADDR, bytes([ads7830_commands[channel]]))
        buf = bytearray(1)
        i2c.readfrom_into(ADS7830_ADDR, buf)
        return buf[0]
    except Exception as e:
        print("I2C error:", e)
        return 0
    finally:
        i2c.unlock()

# Dead-zone thresholds
CENTER   = 128
DEADZONE = 20
UPPER    = CENTER + DEADZONE
LOWER    = CENTER - DEADZONE

last_cmd = None
while True:
    # Read all four axes
    fb      = read_ads7830(1)
    strafe  = read_ads7830(0)
    turn    = read_ads7830(2)
    arm_fb  = read_ads7830(5)
    claw    = read_ads7830(4)
    arm_ud  = read_ads7830(7)

    # Decide on one-byte cmd
    cmd = None
    if   fb     > UPPER: cmd = b"b"
    elif fb     < LOWER: cmd = b"f"
    elif strafe > UPPER: cmd = b"l"
    elif strafe < LOWER: cmd = b"r"
    elif turn   > UPPER: cmd = b"p"
    elif turn   < LOWER: cmd = b"q"
    elif arm_fb > UPPER: cmd = b"c"
    elif arm_fb < LOWER: cmd = b"a"
    elif claw   > UPPER: cmd = b"y"
    elif claw   < LOWER: cmd = b"z"
    elif arm_ud > UPPER: cmd = b"e"
    elif arm_ud < LOWER: cmd = b"d"

    # LOGIC FIX: 
    if cmd is not None:
        # 1. If it's an arm/claw command (a, c, d, e, y, z), ALWAYS send it to keep moving
        if cmd in [b"a", b"c", b"d", b"e", b"y", b"z"]:
            radio.send(cmd)
            print("TX (Streaming) →", cmd)
        
        # 2. For driving/turning, only send if it's a change (prevents jitter)
        elif cmd != last_cmd:
            radio.send(cmd)
            print("TX (Chassis) →", cmd)
            
    # 3. If we just let go of the stick, send "stop" once
    elif last_cmd is not None:
        radio.send(b"s")
        print("TX → STOP")

    last_cmd = cmd
    
    # Speed this up slightly for smoother arm movement
    # 0.05 is usually the "sweet spot" for responsiveness
    time.sleep(0.05)

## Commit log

2024-12-31 Edit folder structure & Add empty folder for CAD files
2024-12-31 Edit folder structure & Add guide for installing neccessary libraries on the raspberry pi zero
2025-01-01 Add setup guide for rpi pico
2025-08-19 CAD Files added
    [remote_assembled.step]
2025-10-21 Minor edits
    [robot_wiring_diagram.fzz]
2026-02-22 Bug Fixes
    [robot_wiring_diagram.fzz, robot_wiring_diagram_old.fzz]
2026-02-26 Repo file organization edits
    [remote_assembled.step, robot_assembled.step]
